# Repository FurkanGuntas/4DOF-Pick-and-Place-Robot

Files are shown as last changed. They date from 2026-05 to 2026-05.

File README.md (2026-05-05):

# 4-DOF RRRR Robotic Arm Design, Simulation, and Implementation

Robot in Action

## Project Overview
This repository contains the complete design, mathematical modeling, control simulation, and physical implementation of a custom 4-Degree-of-Freedom (DOF) robotic arm. I designed this manipulator specifically with an RRRR configuration to execute industrial pick-and-place tasks. This project is my theoretical and practical experience, starting with the derivation of kinematic and dynamic equations, progressing to MATLAB/Simulink simulations, and culminating in the construction of a physical prototype using 3D-printed PLA parts and an ESP32 microcontroller.

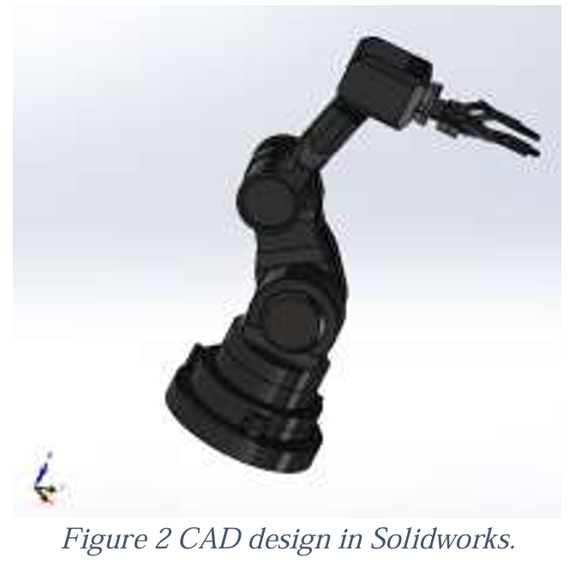
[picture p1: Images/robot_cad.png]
CAD Model


## Mathematical Modeling & Kinematics
A significant portion of this project was dedicated to establishing a rigorous theoretical foundation for the manipulator's movements.

*   **Forward Kinematics:** I utilized the Denavit-Hartenberg (D-H) convention to systematically assign coordinate frames to each joint. By defining the twist angles, link lengths, offsets, and joint angles, I generated the D-H table and computed the homogeneous transformation matrices. This allowed me to accurately map the end-effector's position and orientation relative to the base frame.

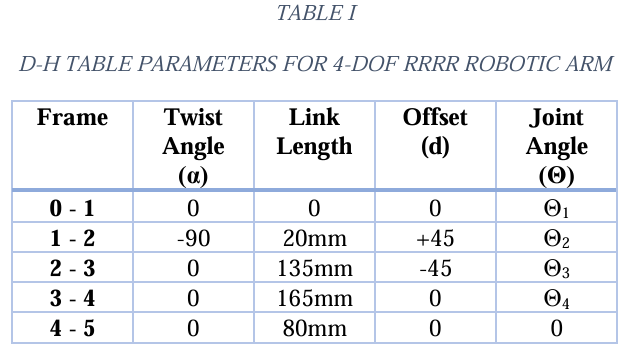
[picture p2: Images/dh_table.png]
D-H Table


*   **Inverse Kinematics:** To determine the necessary joint angles for a desired end-effector position, I implemented a geometric approach. To simplify the complexity of the 3D space, I decoupled the analysis: I calculated the first joint's angle based on the horizontal (X-Y) plane and analyzed the remaining three joints on a 2D planar projection (Z-X plane).
*   **Dynamics:** I derived the complete dynamic model, calculating the Inertia Matrix, Coriolis and Centrifugal forces, and Gravity terms. *Note: To keep the theoretical model within a manageable scope for the initial simulation, motor friction coefficients (Coulomb and viscous) were assumed to be zero.*

## Control and Simulation (MATLAB/Simulink)
To validate the mathematical models and test control strategies before hardware implementation, I built a comprehensive simulation environment in MATLAB and Simulink.

*   **Physical Modeling:** Instead of directly importing the CAD files, I constructed the mechanical properties of the robot (representing links and revolute joints) utilizing Simscape Multibody blocks.
*   **PID Control:** I designed and tuned independent PID controllers for each joint. These controllers calculate the necessary torques to minimize angular positioning errors and ensure stable motion.
*   **Robustness Testing:** To evaluate the system's stability, I injected random external disturbance signals into the simulation and verified the PID controllers' ability to compensate for these unexpected forces.

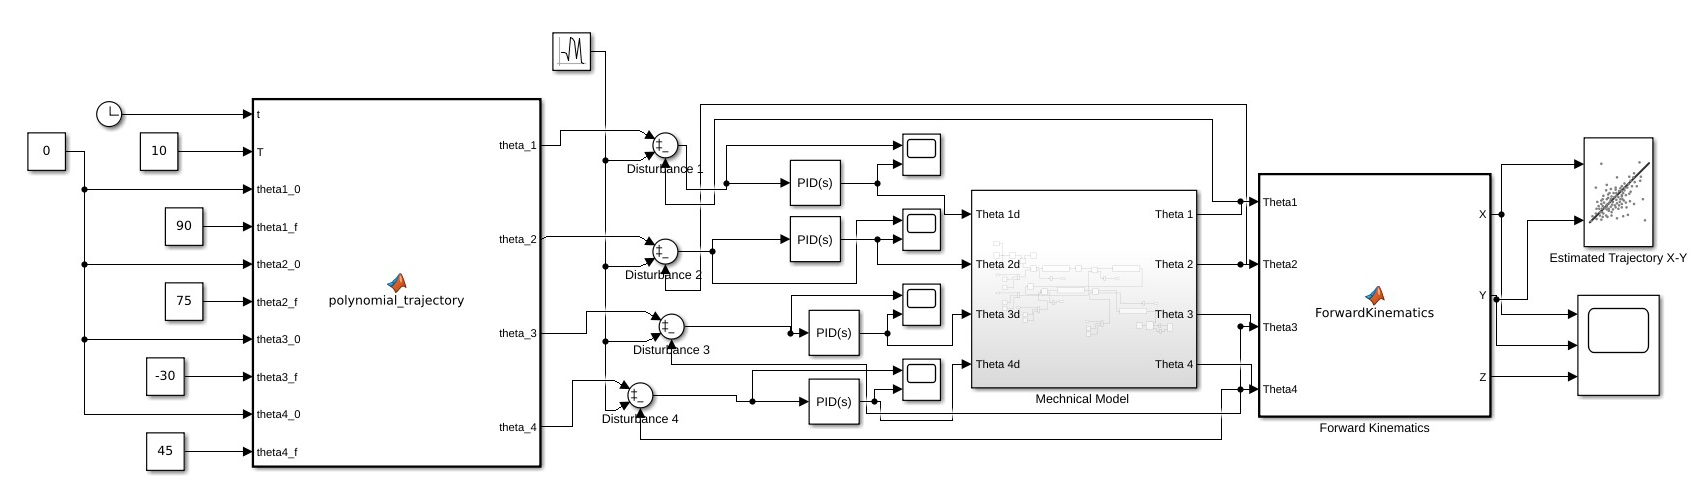
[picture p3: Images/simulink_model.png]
Simulink Model


## Hardware & Prototyping
To bring the theoretical models to life, I constructed a functional physical prototype.

*   **Manufacturing:** I 3D-printed the structural links using PLA filament, providing a lightweight yet rigid frame suitable for rapid prototyping.
*   **Electronics:** The arm is actuated by four DS3225 (270-degree) servo motors. I programmed an ESP32 microcontroller to generate the precise PWM signals required to drive these motors. A dedicated 5V external power supply with a common ground was integrated via a breadboard to ensure stable current delivery to the actuators.

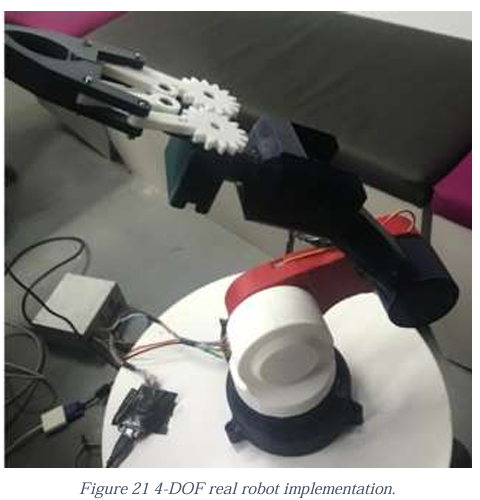
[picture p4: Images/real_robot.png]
Real Robot Prototype


## Limitations & Simplifications
While the project successfully demonstrates core robotics principles, I acknowledge a few approximations and limitations in the current build:
1.  **Friction Assumptions:** The theoretical dynamic equations were simplified by ignoring joint friction.
2.  **End-Effector Integration:** Although I designed and mounted a mechanical gripper, it has not yet been fully integrated into the electronic control loop or the kinematic code for automated operation.
3.  **Real-Time Trajectory Execution:** Currently, the smooth 5th-order polynomial trajectories are calculated perfectly in MATLAB simulations. However, seamlessly streaming these high-resolution, time-dependent angular targets to the ESP32 for real-time hardware execution remains an area for future optimization.

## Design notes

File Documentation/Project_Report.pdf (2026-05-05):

# Four Degrees of Freedom Robotic Arm Design and Implementation

Furkan Güntaş, Orhan Köseoğlu, Emircan Yücel Kadir Has University

Abstract— This project focuses on the design and implementation of a 4-degree-of-freedom (DOF) robotic arm for pick-and-place tasks. The robot has a lightweight design and uses Denavit-Hartenberg parameters for precise kinematic modeling. The CAD model includes 3D design details of the robotic arm. The design combines forward and inverse kinematics, dynamic modeling, actuator selection, and PID control to ensure stable operation. The system uses PID algorithms implemented in SIMULINK and trajectory simulations performed in MATLAB for precise motion control. Safety and efficiency are prioritized to ensure reliable manipulation within the defined working area.

Index Terms— Denavit-Hartenberg, Jacobian Matrix,
Forward | Kinematics, | Manipulator | Dynamic, | Inverse
Kinematics, PID Control, MATLAB, SIMULINK.
I. INTRODUCTION

he primary objective of this project is to design and implement a 4-degree-of-freedom (DOF) robotic arm for performing pick-and-place operations, focusing on both practical application and theoretical foundation. Central to the project is the development of a comprehensive kinematic and dynamic model of the robotic system. Utilizing Denavit-Hartenberg (DH) parameters, the forward and inverse kinematics are derived to ensure precise end-effector positioning. The dynamic analysis incorporates critical components such as the inertia matrix, Coriolis forces, and gravitational effects, enabling the accurate calculation of joint torques and accelerations. These calculations were fundamental in guiding actuator and microcontroller selection to ensure optimal performance and reliability. The control system employs a PID algorithm designed in the SIMULINK environment to stabilize the system and mitigate disturbances during operation. Custom trajectory planning was carried out in MATLAB using high-order polynomials to ensure smooth and efficient motion across all joints, with detailed evaluations of angular positions, velocities, and accelerations. This project adopts a modular and user-centered approach, allowing future customization in DOF and parameter definitions. The methodology integrates CAD modeling, control system design, and dynamic analysis to deliver a versatile and high-performing robotic arm. By combining simulation and practical implementation, the project aims to bridge the gap between theoretical concepts and real-world robotic applications, providing valuable insights for advanced robotics design and control.
II. GENERAL SYSTEM DEFINITIONS AND DETAILS
A. Task Requirements

The manipulator designed for this project has an RRRR configuration, where all joints are revolute. It has a simple gripper-like end effector designed to pick up objects from one location and place them in another. The manipulator moves in a three-dimensional space with four degrees of freedom. This configuration allows the robot to lift and carry objects autonomously.

Its main function is to improve efficiency and speed in industrial applications such as assembly lines or material handling processes. For example, in an automotive assembly line, parts like hoods or fenders are positioned autonomously and mounted onto vehicles with high precision. Similar systems are also widely used in industries such as furniture manufacturing, aerospace production, and other industrial fields.

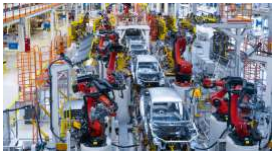
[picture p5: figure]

Figure 1 Example of 4-DOF RRRR robotic arm.

B. CAD Model

Every component of the manipulator system, including the gripper-like end effector, is fully represented in the CAD model (See Figure 2). The manipulator's RRRR configuration is reflected in the model, with revolute joints enabling precise movements. SolidWorks was chosen as the CAD program due to its advanced capabilities and its suitability for designing complex robotic systems in this project.

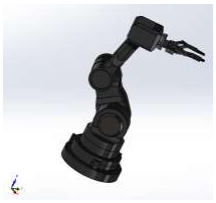
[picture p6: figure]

Figure 2 CAD design in Solidworks.

T

C. Degrees of Freedom

The manipulator’s four degrees of freedom (DoFs) enable it to move freely along the X, Y, and Z axes, providing comprehensive motion capabilities in three-dimensional space. In addition to translational movement, the manipulator’s rotational ability around the Z axis allows it to perform tasks such as box organization with greater flexibility and precision. The rotation of the end effector is achieved through revolute joints, which play a crucial role in enhancing the manipulator's overall functionality. These joints enable the system to perform rotational movements that are essential for tasks requiring specific orientations, such as arranging boxes in preferred configurations.

Having more than three degrees of freedom offers significant advantages. It enhances the manipulator's flexibility and efficiency, enabling it to adapt to a wide variety of tasks. This added capability allows for unique and optimized approaches to box organization, making the manipulator a versatile and effective tool in various applications.

D. Materials Selection and Production

When choosing the material for the robot’s links, consideration was given to variables such as maximum torque, overall size, and the expected load, represented by the tasks the manipulator is designed to perform. Density, Young’s modulus, and thermal expansion coefficient are key mechanical properties of the selected materials, ensuring optimal performance in terms of precision and durability. These factors are crucial to maintaining the manipulator's functionality across diverse operational conditions.
For the prototype phase of this project, PLA (polylactic acid) material was chosen due to its cost-effectiveness, ease of
manufacturing, | and | compatibility | with | 3D | printing
technologies. PLA’s lightweight nature facilitates the creation of quick and functional prototypes suitable for experimental evaluation.
However, for industrial applications, aluminium is a more suitable material for the robot’s links. Aluminium’s lightweight design allows for quick and precise movements while maintaining structural integrity.

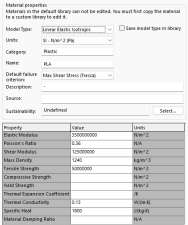
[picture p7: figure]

Figure 3 Defining PLA material in Solidworks.

In the prototype phase of the project, the links were manufactured using PLA material and 3D printing. This method is cost-effective, allows for fast production, and helps test and improve the design. For industrial applications, aluminium and CNC machining will be used. Aluminium is lightweight, durable, and easy to machine, which improves the robot’s efficiency. The design includes servo motors, fasteners, and standard gripper mechanisms. These components ensure the robot performs its movements accurately and efficiently.

E. Actuators and Additional Components

The manipulator system integrates four DS3225 servo motors as the primary actuators, driven by an ESP32 microcontroller for precise and reliable control. These servo motors provide smooth and accurate movement for the robotic arm’s revolute joints, ensuring efficient operation across various tasks. The ESP32 offers flexibility in controlling the system and allows for potential expansion with additional sensors or peripherals.
To enhance the system’s functionality and safety, additional components like cameras or other sensors can be integrated. For example, cameras can assist in object detection, path planning, or identifying obstacles in the workspace. Obstacle detection sensors, such as ultrasonic or infrared sensors, can further improve the manipulator's safety by preventing collisions during operation. These enhancements would provide the manipulator with advanced capabilities, creating a more intelligent and secure working environment.

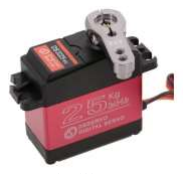
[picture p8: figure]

Figure 4 DS3225 Servo Motor

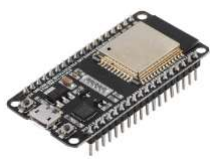
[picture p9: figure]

Figure 5 ESP 32

III. DETAILED CALCULATIONS

A. Forward Kinematics

As the first step, we worked on the forward kinematics of the robot. To describe the robot, we used the Denavit-Hartenberg (DH) notation. The initial task was to assign coordinate frames for each joint to relate them to the world reference frame. These frames were prepared according to the DH notation, allowing us to mathematically represent the movements of the robot's joints.
Based on the defined reference frames, the link variables (link angle, twist angle, link length, and link offset) were identified, and the DH table was constructed. Using the DH table, homogeneous transformation matrices were derived, enabling transformations from any joint to the end-effector. These transformation matrices clearly define the forward kinematics of the system. The DH table for the designed robotic arm1 is provided below, and these transformation matrices clearly define the forward kinematics of the system.

TABLE I

D-H TABLE PARAMETERS FOR 4-DOF RRRR ROBOTIC ARM

Frame | Twist Angle (α) | Link Length | Offset (d) | Joint Angle (Θ)
0 - 1 | 0 | 0 | 0 | Θ1
1 - 2 | -90 | 20mm | +45 | Θ2
2 - 3 | 0 | 135mm | -45 | Θ3
3 - 4 | 0 | 165mm | 0 | Θ4
4 - 5 | 0 | 80mm | 0 | 0

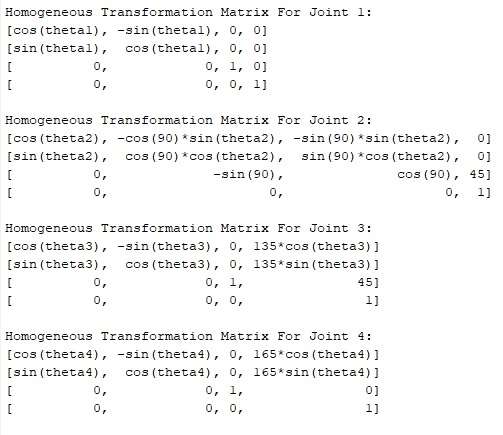
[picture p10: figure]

B. Inverse Kinematics

To calculate the joint angle values in inverse kinematics, the second method, the geometric approach, was chosen over the algebraic method. To reduce the complexity of the system, the first joint was analyzed separately from the second, third, and fourth joints. This allowed the first joint to be analyzed in two dimensions during the geometric analysis.

When the remaining second, third, and fourth joints were examined as a group, it was observed that their motion was confined to two-dimensional movement in the y-x plane. Consequently, the geometric analysis of this joint group was also performed in two dimensions, simplifying the derivation of the inverse kinematic equations significantly.

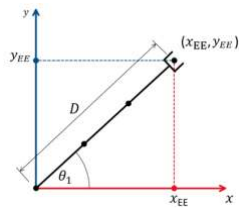
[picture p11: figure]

Figure 7 Geometrical analysis of the first joint.

The X-Y plane is considered the horizontal plane in this analysis. Movement within this horizontal plane is solely achieved by the first joint. The angular displacement of this joint is directly dependent on the X and Y coordinates. Therefore, when deriving the equation for the first joint, the angle is calculated as the arctan of the X and Y coordinates. Based on the representation shown in Figure 6, this approach ensures that the angular position of the first joint is accurately determined with respect to the horizontal plane.

When the remaining second, third, and fourth joints were examined, it was observed that their movement was confined to the Z-X plane. As a result, a two-dimensional analysis was conducted.

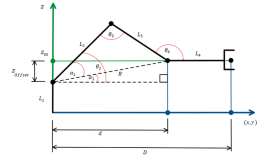
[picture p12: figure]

Figure 8 Geometrical analysis of the last three joints.

Figure 6 Transformation matrices for each joint.

Based on the triangle formed by the second, third, and fourth joints shown in Figure 7, the following equations were derived. Using these equations, the formulas for the joint angles in inverse kinematics were obtained.

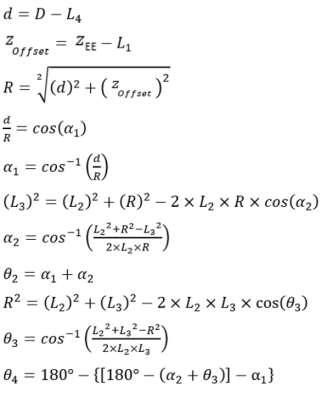
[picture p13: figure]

C. Forward and Inverse Dynamics

The torque calculation required for the system has been performed considering the force-torque relationship. These steps are explained sequentially below.

Figure 9 Force- Torque relationship.

This equation relates the external torque Fext applied on the robotic joints to the external force at the end-effector. The transpose of the Jacobian matrix acts as a mapping from the force applied in Cartesian space to the joint space. This is essential for including external effects, such as forces and torques, in the system dynamics.

1) Full Dynamics Equation

Figure 10 Torque formula.

This is the equation of motion for robotic systems. Each term represents a distinct dynamic contribution:

Where:

- n is the number of joints.
- q(n×1) are the joint angles or distances.
- (q)(n× 1) are the joint velocities.
- (q)(n× 1) are the joint accelerations.
- τ(n×1) is the joint torques or forces.
- F(6×1) is the Cartesian force or torque applied on the end-effector.
- JT
(n× 6) is the transpose of the Jacobian of the manipulator.
- M(q)(n×n) is the inertial matrix of the robot, depending on the configuration of the robot (joint angles).
- C(q, ˙ q)(n×n) is the Coriolis and centrifugal matrix, dependent on configuration and joint velocities.
- G(q)(n×1) is the vector of gravity terms for each joint.

In this format, we only ignored the friction terms because they depend on the motor’s coulomb viscous friction coefficients.

2) Operational Space Inertia Matrix
This equation transforms the joint space inertia matrix M(Θ) to operational (Cartesian) space. It ensures that the inertia matrix reflects the dynamics in the end-effector space, enabling better control and understanding of the forces and accelerations experienced in operational tasks.

Mx(Θ): Cartesian mass matrix

J(Θ): Jacobian matrix

J⁻¹(Θ): Inverse of the Jacobian matrix

Jᵀ(Θ): Transpose of the inverse Jacobian matrix

M(Θ): Joint-space mass matrix

Θ: Joint-space position vector

3) Coriolis and Centrifugal Matrix

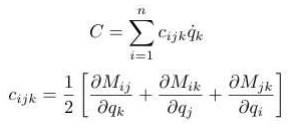
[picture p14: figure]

These coefficients define the elements of the Coriolis matrix, capturing velocity-dependent effects. The Coriolis forces arise due to the motion of multiple robot links and the interaction between their velocities. The partial derivatives of the inertia matrix M with respect to joint positions determine these coefficients.

4) Gravity Terms

This equation maps the gravity vector G(Θ) from joint space to operational (Cartesian) space. It enables accurate compensation for gravity effects on the end-effector, especially in tasks requiring precise positioning or manipulation. Also it calculates the gravitational torque gi acting on joint i. The gravitational contribution of each link j depends on its mass mj the gravitational acceleration g0

p
in the base frame, and the Jacobian Jj. Summing these contributions provides the total gravitational torque on each joint.

IV. ELECTRONIC UNIT DESIGN

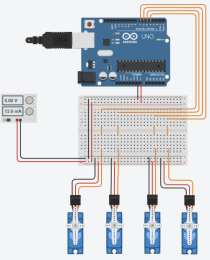
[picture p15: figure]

Figure 11 Electronic Control Unit Design.

In this project, the electronic control unit for the robotic arm is designed using an ESP32 microcontroller, a breadboard, and four DS3225 servo motors. The system is powered by an external 5V power supply to ensure stable operation for all servo motors. The ESP32 acts as the main controller, sending PWM signals to the servo motors to control their movement. The positive and ground terminals of the external power supply are connected to the breadboard, distributing power to the servo motors. Each servo motor is connected to the breadboard, where the red wire (positive) is connected to the positive rail, the brown wire (ground) is connected to the ground rail, and the orange wire (signal) is connected to a PWM output pin on the ESP32. This configuration enables precise control of the robotic arm’s joints while ensuring the motors receive sufficient power for optimal performance.

IV. CODING THE MICROCONTROLLER

To control end effector positions in the microcontroller, a servo motor control algorithm is used. Each servo motor is assigned a target position, and an interpolation function is used to gradually reach that target. The end effector's positions are determined based on user inputs or a predefined trajectory plan.

The main steps that our microcontroller have are:
- Define the initial positions.
- Set the target positions.
- Gradually move each servo from the current position to the target position in small steps.
- Once all servos reach their positions, stabilize the system and continuously monitor for external changes.

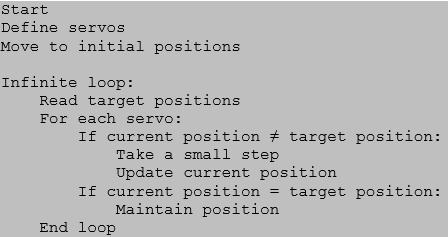
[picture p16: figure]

Figure 12 Pseudocode of Servo Motor Controllers.

The loop frequency is usually set to 50 Hz (20 ms loop time). We choose this frequency because servo motors usually operate on a 50 Hz PWM signal and provide smooth movements at this frequency. The loop is fast enough to
provide | timely | feedback | without | overloading | the
microcontroller.
V. MATLAB – SIMULINK SIMULATION

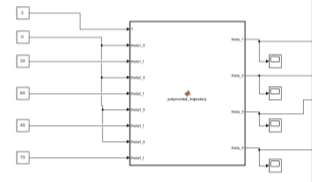
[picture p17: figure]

Figure 13 Polynomial Trajectory

We use polynomial equations (5th degree) to calculate the joint angles of a robot manipulator. The input angles are processed to create a smooth trajectory for each joint based on predefined start and end positions, providing smooth motion. This system provides the angular positions of the robot arm joints as a function of time, which is critical for simulating realistic and smooth motions.

Figure 14 Mechanical Model and Forward Kinematics.

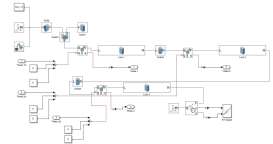
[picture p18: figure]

Figure 15 Mechanical Model Detail.

We designed the mechanical model in Simulink using block manipulation, since CAD designs cannot be imported directly. Blocks represent the physical structure of the robot, including links and joints. We implemented forward kinematics using transformation matrices. This allows me to calculate the X, Y, and Z coordinates of the end effector based on the joint angles. The forward kinematics block determines the position of the robotic arm in the workspace, allowing its motion to be accurately simulated.

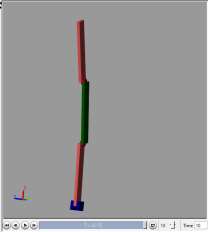
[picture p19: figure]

Figure 16 Simulation of Robotic Arm in Simulink.

The simulation visually shows the movement of the robotic arm according to the given joint angles and PID controller values. The 3D environment allows me to observe how the arm moves and how the control parameters affect its trajectory.

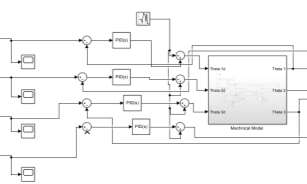
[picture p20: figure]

Figure 17 PID Implementation.

We implemented PID controllers to dynamically adjust the joint angles of the robotic arm.
Advantages of PID Controllers:
- They provide smooth and stable motion by minimizing the errors in the joint angles.
- They improve the response time of the system and reduce oscillations.

Also, we added the disturbance to test the robustness of the system. The PID controller adjusts the system in real time to compensate for the distortions and ensures that the arm remains on the desired path.

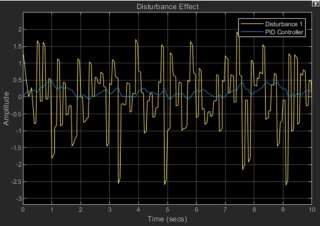
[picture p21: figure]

Figure 18 Disturbance effects and PID.

VI. APPLYING TRAJECTORY

The trajectory is obtained by using fifth-order polynomial equations as shown in the provided formula. These equations are used to calculate the trajectory coefficients (a0 to a5) for each joint. The coefficients are derived from boundary conditions including the starting and ending positions, velocities, and accelerations. By including these conditions, we ensure a smooth transition between the starting and ending points of the motion while maintaining continuous position, velocity, and acceleration.

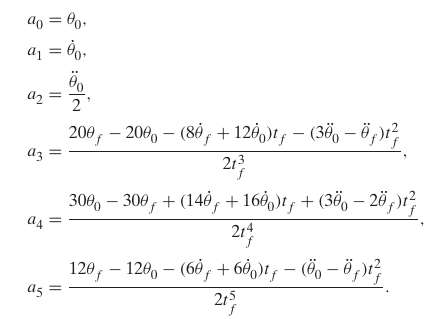
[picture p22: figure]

Figure 19 Coefficient calculation for trajectory equations.

The code takes as input the values θ0, θf, and T (total time). Using these, the polynomial coefficients are calculated directly from the equations. These coefficients (a0 to a5) are then applied to calculate the position, velocity, and acceleration at each time step. This approach ensures that the robotic arm moves smoothly, avoiding sudden changes in motion.

By integrating these equations into the code, we aim for the closest trajectory to the optimum against the physical constraints of the robot, such as avoiding sudden jolts or stresses in mechanical components. This method makes the movement safe, efficient, and realistic for the task. The results are plotted for each joint to visualize the trajectories, and user-defined inputs significantly affect the result, such as the range and duration of the movement.

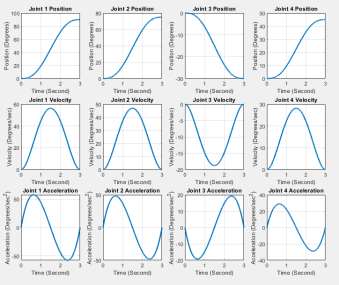
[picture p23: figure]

Figure 20 Trajectory results graph for each joint.

VIII. REAL TIME APPLICATION

We built a real-life robotic arm The robot's design includes precise motion control and stability. While the end-effector mechanism has been designed and integrated, it has not been fully utilized in the current stage of implementation.

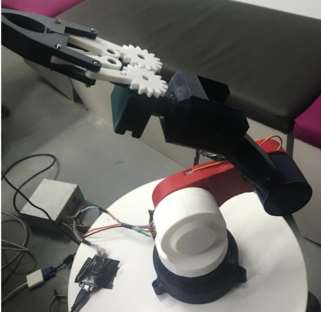
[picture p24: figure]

Figure 21 4-DOF real robot implementation.

VII. CONCLUSION

In conclusion, this project has successfully demonstrated the design and implementation of a 4-DOF robotic arm, integrating precise kinematic modeling with efficient electronic control. The forward kinematics of the system were modeled using Denavit-Hartenberg (DH) parameters, allowing the end-effector's position and orientation to be accurately calculated through transformation matrices. Inverse kinematics were solved using a geometric approach, simplifying the complexity of the calculations by analyzing joint groups in two-dimensional planes. This provided a streamlined and effective method for determining joint angles to achieve desired end-effector positions.

The electronic control unit, built with an ESP32 microcontroller and DS3225 servo motors, seamlessly translates these kinematic solutions into precise motion. The use of a 5V power supply ensures reliable operation of the motors, while the modular nature of the design allows for future upgrades, such as integrating sensors for obstacle detection or advanced feedback systems. This combination of advanced kinematic modeling and robust electronic control highlights the potential of the robotic arm to perform complex tasks with accuracy and efficiency, laying a strong foundation for future enhancements and applications in industrial or academic settings.

REFERENCES

[1] P. Shahverdi and M. T. Masouleh, “A Simple and Fast Geometric Kinematic Solution for Imitation of Human Arms by a NAO Humanoid Robot,” in Proceedings of the 4th International Conference on Robotics and Mechatronics, Tehran, Iran, Oct. 26-28, 2016, pp. 572-577,

[2] J. J. Craig, Introduction to Robotics: Mechanics and Control, 3rd ed. Harlow, Essex, England: Pearson Education, 2014, pp. 1

–360.

[3] M. Kaur, S. Sondhi, and V. K. Yanumula, “Kinematics Analysis and Jacobian Calculation for Six Degrees of Freedom Robotic Arm,” in Proceedings of the 17th India Council International Conference
(INDICON), | New | Delhi, | India, | Dec. | 2020, | pp. | 1
-6, | doi:
10.1109/INDICON49873.2020.9342093.

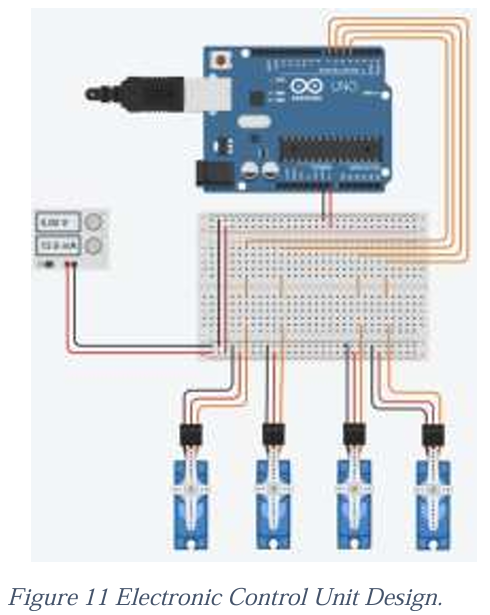
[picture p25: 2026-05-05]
Images/electric_control_unit.png

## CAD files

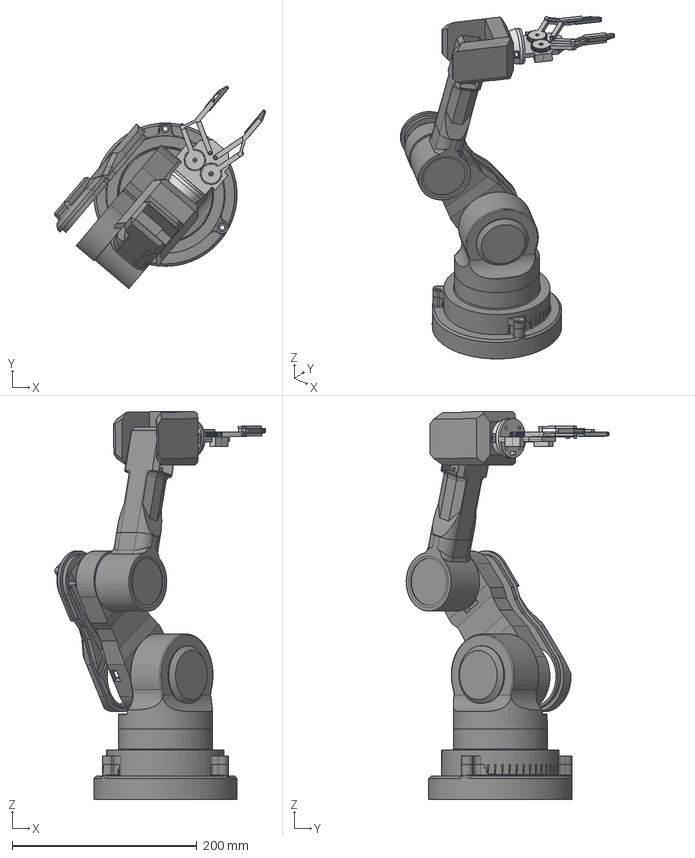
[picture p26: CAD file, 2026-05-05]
CAD_Models/Assembly 1.step
228.4 x 219.1 x 419.6 mm
Spur gear (29 teeth) x 2
